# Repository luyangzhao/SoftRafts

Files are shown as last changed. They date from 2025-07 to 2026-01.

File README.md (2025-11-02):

# **SoftRafts: Floating and Adaptive Soft Modular Robots**

## 🚀 Overview

**SoftRafts** is a modular soft robotic system that integrates rigid 3D-printed components, soft foam, a cable-driven actuation mechanism, and a propeller for aquatic mobility. Using permanent magnets for fast inter-module connections, each unit can **bend**, **steer**, **connect**, and operate collectively in a swarm. It serves multiple functions, such as:

* Acting as a **gripper** to retrieve debris from water  
* Assembling into a **floating raft** for drone landing  
* Forming a **snake-like chain** that transitions between land and water  
* Working collaboratively to **transport payloads**

This platform demonstrates how soft deformation and modularity enable adaptive, multifunctional robotics for real-world aquatic environments.

---

## 📁 Repository Structure

```
SoftRafts/
│
├── CAD/                     # STL models for 3D printing
│   └── softraft.png         # Render of full assembled raft
│
├── firmware/                # ESP32-S2 microcontroller firmware
│   └── firmware_softrafts.ino
│
├── software/                # Control, analysis, and visualization notebooks
│   ├── SoftRafts-control.ipynb
│   ├── snake--curve.ipynb
│   └── gaits_data_processing.ipynb
│
├── raw_gaits_data/          # Raw positional and orientational data (6 gaits)
│   ├── forward_data.json
│   ├── backward_data.json
│   ├── left_front_data.json
│   ├── right_front_data.json
│   ├── left_back_data.json
│   ├── right_back_data.json
│   └── README.md
│
├── figures/                 # Auto-generated plots (e.g., Figure 8)
│   └── plot_comparison.png
│
├── LICENSE
└── README.md
```

---

## 🧱 CAD Models

The `CAD/` folder contains 3D-printable STL models for all robot parts:

* `Whole_SoftRaft.stl` — complete raft assembly (for reference)  
* `Board.stl`, `Middle.stl`, `Tail.stl`, `Head.stl` — core structural modules  
* `Motor.stl`, `Motor Cover.stl` — motor housing components  
* `Winch.stl` — for cable-driven actuation  
* `Cover.stl` — protective enclosure for electronics  
* `softraft.png` — visual rendering of the assembled robot  

---

## 🔧 Firmware

Located in the `firmware/` folder, `firmware_softrafts.ino` is the control firmware for the **ESP32-S2** microcontroller.

**Features:**
* Wi-Fi web server interface for motor control (port 80)  
* OTA (Over-the-Air) firmware updates via ArduinoOTA  
* Encoder-based position feedback and calibration  
* REST-style HTTP commands for live control (`/set`, `/status`, `/pause`, etc.)

> Upload via the **Arduino IDE** with the ESP32-S2 board selected.

---

## 🧠 Software

The `software/` folder contains all Python-based notebooks for **robot control, gait data analysis, and visualization**.

### Included Notebooks:
- **`SoftRafts-control.ipynb`** — Wi-Fi control interface for the SoftRaft robot  
- **`snake--curve.ipynb`** — Geometry and curvature visualization of chained modules  
- **`gaits_data_processing.ipynb`** — Reproducible gait data processing and analysis notebook for Figure 8

The analysis notebook:
* Loads raw data from `raw_gaits_data/`  
* Performs coordinate transformation to the local reference frame  
* Removes outliers and computes cluster centers  
* Generates the comparison figure automatically (`figures/plot_comparison.png`)

> Requires Python ≥ 3.7 with `numpy`, `matplotlib`, `requests`, `pandas`, and `notebook`.

---

## 📊 Raw Data

The `raw_gaits_data/` folder contains six JSON files corresponding to different gaits  
(forward, backward, left-front, right-front, left-back, right-back).  
Each file contains 35 recorded trials of positional and orientational data (in cm and degrees).

A detailed `README.md` in that folder explains:
* The meaning and units of each field  
* How to reproduce Figure 8 using the analysis notebook in `software/`

---

## ⚙️ Setup Instructions

1. Clone the repository:
   ```bash
   git clone https://github.com/SMILE-Robotics-Lab/SoftRafts.git
   cd SoftRafts/software
   ```

2. Create and activate a virtual environment:
   ```bash
   python3 -m venv venv
   source venv/bin/activate
   ```

3. Install dependencies:
   ```bash
   pip install numpy matplotlib pandas requests notebook
   ```

4. Launch Jupyter:
   ```bash
   jupyter notebook
   ```

---

## 📬 Contact

For questions, collaboration, or reproducibility assistance:

📧 **Luyang Zhao** — [luyangz@clemson.edu](mailto:luyangz@clemson.edu)  
📧 **Yitao Jiang** — [yitao.jiang.gr@dartmouth.edu](mailto:yitao.jiang.gr@dartmouth.edu)

---

## 📄 License

This project is licensed under the **MIT License**.

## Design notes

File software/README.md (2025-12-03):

# 🧠 SoftRafts Software

This folder contains Python-based control, analysis, and visualization notebooks for **SoftRafts**, supporting real-time robot control, geometric behavior visualization, and data processing for gait characterization.

---

## 📁 Files

### `SoftRafts-control.ipynb`

A **Jupyter notebook interface** for controlling the SoftRaft robot wirelessly via Wi-Fi.

🔧 **Features**:
* Sends HTTP commands (e.g., `/set`, `/status`, `/pause`) to the onboard ESP32  
* Adjusts motor positions, power, and direction  
* Displays returned status (position, power, battery, etc.)  
* Supports interactive testing of firmware APIs  

📦 **Requirements**:
* `requests`
* `IPython.display`
* Python ≥ 3.7

---

### `snake--curve.ipynb`

A notebook for **visualizing the geometry and curvature** of multi-module snake-like raft configurations.

📐 **Highlights**:
* Computes bend angles (`θ`) and link lengths (`s1`, `s2`) using trigonometry  
* Draws intermediate bend points (`C`, `D`) between modules  
* Propagates curvature along chained modules  
* Estimates directionality and turning radius  

📦 **Requirements**:
* `numpy`
* `matplotlib`

---

### `gaits_data_processing.ipynb`

A **standalone Jupyter notebook** that processes and analyzes the raw gait data used in the paper (Figure 8).  
It provides a fully reproducible pipeline from raw measurements to the final figure.

📊 **Functions**:
* Loads the six JSON files from [`../raw_gaits_data/`](../raw_gaits_data/)  
* Transforms data from distance/orientation changes into a standardized local reference frame  
* Removes outliers using the IQR method  
* Computes gait-specific cluster centers  
* Generates and saves the comparison figure (`../figures/plot_comparison.png`)  

📦 **Requirements**:
* `numpy`
* `matplotlib`
* `json`
* `pathlib`
* `pandas`

---

### `workspace/`

A **MATLAB** subfolder containing scripts for structural and workspace analysis of SoftRafts.  
Run **`MAIN_space.m`** to compute and visualize the robot’s workspace and deformation behavior under different prestress configurations.

📐 **Highlights**:
* Implements tensegrity equilibrium and stiffness matrix calculations  
* Visualizes deformation, workspace boundaries, and adaptation strategies  
* Includes supporting MATLAB functions for prestress design and plotting  

> 💡 Tested with MATLAB R2023a; requires the Optimization Toolbox.

---

## 🧰 Setup

Create a virtual environment and install dependencies:

```bash
python3 -m venv venv
source venv/bin/activate
pip install numpy matplotlib requests pandas notebook

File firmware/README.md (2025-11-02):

# 📡 SoftRafts Firmware

This folder contains the Arduino-based firmware (`firmware_softrafts.ino`) for the **ESP32-S2** microcontroller onboard each SoftRaft module. It enables real-time wireless control of motors, position feedback via encoders, and OTA (Over-the-Air) firmware updates.

---

## 🔌 Features

* ✅ Controls **3 motors** (2 motor actuators, 1 propulsion)
* ✅ Reads **quadrature encoders** for M1 and M2
* ✅ Supports **position control**, **power modulation**, and **direction switching**
* ✅ Hosts a **web server** on port `80` for HTTP-based control
* ✅ Supports **OTA updates** using `ArduinoOTA`
* ✅ Reports **battery voltage**, motor errors, and pause state

---

## 📁 File

* `firmware_softrafts.ino`: Main control firmware for SoftRaft hardware (ESP32)

---

## 🌐 Command Interface (via HTTP GET)

| Command | URL Format | Description |
| --- | --- | --- |
| Status | `/status` | Returns system status (motor position, power, battery, errors) |
| Set Motors | `/set=XXXXXXXXXXXXXX` | Set targets/powers for M1, M2, M3. Format: 8+2+8+2+1+2 hex chars |
| Calibrate | `/calibrate=XY` | Reset M1 and/or M2 encoder to zero |
| Reach Target | `/reach=XY` | Snap current position to target (for M1 and/or M2) |
| Pause/Resume | `/pause=X` | Pause (`1`) or resume (`0`) all motors |

Example:

```
/set=000000640A000000C80A11
```

sets:

* M1 target = 100 (0x00000064), power = 10
* M2 target = 200 (0x000000C8), power = 10
* M3 direction = `1` (forward), power = 17

---

## 📶 Wi-Fi Setup

The ESP32-S2 connects to:

* **SSID**: `BotTest`
* **Password**: `123456789`

You can modify these at the top of `firmware_softrafts.ino`.

Once connected, you can check the IP address and MAC address over your router portal.

---

## ⚙️ First Time Flashing Instructions

1. Open `firmware_softrafts.ino` in the Arduino IDE
2. Select **ESP32S2 Dev Module** as the board
3. Install required library:

   * `ArduinoOTA.h`
4. Connect the ESP32-S2 via USB and upload
5. After upload, monitor via serial to confirm Wi-Fi and OTA readiness

---

## 🔄 OTA Updates

Once connected to Wi-Fi, you can push firmware updates wirelessly using ArduinoOTA. The device will blink its onboard LED during OTA transfer.

---

## 📞 Troubleshooting

* Ensure your router allows devices to connect over 2.4GHz Wi-Fi.
* Use Serial Monitor to debug IP address and errors.

---

## 📜 License

This firmware is released under the [MIT License](../LICENSE).

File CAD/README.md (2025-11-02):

# **SoftRafts CAD Models and 3D Printing Guide**

## 🏗️ Overview

This folder contains **3D models** for all key components of **SoftRafts**, supporting modular design and assembly for soft robotic rafts.

### **🔹 Full SoftRaft Assembly**

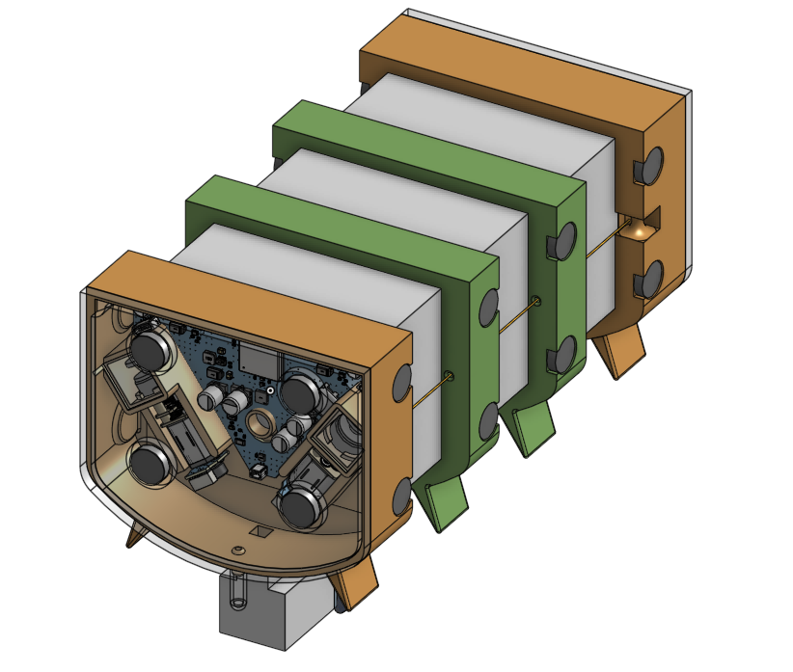
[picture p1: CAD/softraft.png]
SoftRaft Full Assembly


---

## 📂 Files in this Folder

* `Whole_SoftRaft.stl` → Assembled complete raft for reference or full printing.
* `Board.stl` → Main base board structure.
* `Tail.stl` → Rear-end module for propulsion or structure.
* `Middle.stl` → Central body segment for structural extension.
* `Motor Cover.stl` → Protective shell for the motor enclosure.
* `Motor.stl` → Motor housing unit.
* `Cover.stl` → General-purpose cover or enclosure.
* `Winch.stl` → Mechanical winch for tensioning or cable deployment.
* `Head.stl` → Frontal module, possibly for sensor mounting.
* `softraft.png` → Rendered image of the complete SoftRaft assembly.

---

## 🔩 **Component Descriptions**

### **1️⃣ Whole Assembly (`Whole_SoftRaft.stl`)**

* Fully assembled reference model combining all modules.
* Use for **scale check, visualization** prototypes.

---

### **2️⃣ Modular Parts**

#### `Board.stl`, `Tail.stl`, `Middle.stl`, `Head.stl`

* These represent the **core structural elements** of the raft.
* Can be printed and assembled modularly to form the complete raft body.

#### `Motor.stl` & `Motor Cover.stl`

* Designed to house compact **brushless or geared motors** for thrust or steering.

#### `Winch.stl`

* Winch mechanism base to integrate cable or string-based actuation or payload release.

#### `Cover.stl`

* A universal part used to seal components such as battery chambers or electronics.

**🔧 General Printing Guidelines for All Parts:**

* **Material**: PLA or PETG for general use; Resin for waterproof versions
* **Layer Height**: 0.15–0.2 mm
* **Supports**: Enabled for overhangs (e.g., motor housing)

---

## 🔧 **Modifying the CAD Models**

* For Fusion 360 or SolidWorks editing, convert STL to mesh body or re-model using `Whole_SoftRaft.stl` as reference.
* Recommended to re-export assemblies from native CAD format for major modifications.

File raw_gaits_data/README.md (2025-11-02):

# Raw Gait Data for SoftRafts (Used in Figure 8)

This folder contains the **raw positional and orientational data** used to generate **Figure 8** in the paper:  
*“Comparison of x–y positions for different gaits and their corresponding cluster centers with positions and orientations.”*

---

## Folder Contents

| File | Description |
|---|---|
| `forward_data.json` | Raw trajectory data for the forward gait |
| `backward_data.json` | Raw trajectory data for the backward gait |
| `left_front_data.json` | Raw trajectory data for the left-front gait |
| `right_front_data.json` | Raw trajectory data for the right-front gait |
| `left_back_data.json` | Raw trajectory data for the left-back gait |
| `right_back_data.json` | Raw trajectory data for the right-back gait |

Each file contains **recorded trials** of that gait, each stored as one JSON object per line.

---

## Data Format

Every JSON line includes the following fields:

| Key | Description | Unit |
|-----|---|---|
| `robot_id` | Robot identifier (constant = 2) | — |
| `tag_id` | AprilTag marker ID used for tracking | — |
| `start_x`, `start_y`, `start_theta` | Start position and orientation in the world (AprilTag) frame | **cm**, degrees |
| `goal_x`, `goal_y`, `goal_theta` | Final position and orientation after one gait cycle | **cm**, degrees |

All positions are expressed in the **AprilTag world coordinate frame**,  
with the robot’s initial pose standardized to \((0, 0, 0)\) and the orientation parallel to the x-axis.

---

## Processing and Reproduction

The Jupyter notebook [`../software/gaits_data_processing.ipynb`](../software/gaits_data_processing.ipynb)  
loads these JSON files, removes outliers, computes cluster centers,  
and reproduces **Figure 8** (the comparison of \(x\)–\(y\) positions and orientations).

Example usage:

```python
import json
from pathlib import Path

DATA_DIR = Path("../raw_gaits_data")
with open(DATA_DIR / "forward_data.json") as f:
    data = [json.loads(line) for line in f]

print(f"Loaded {len(data)} trials.")
print(data[0])

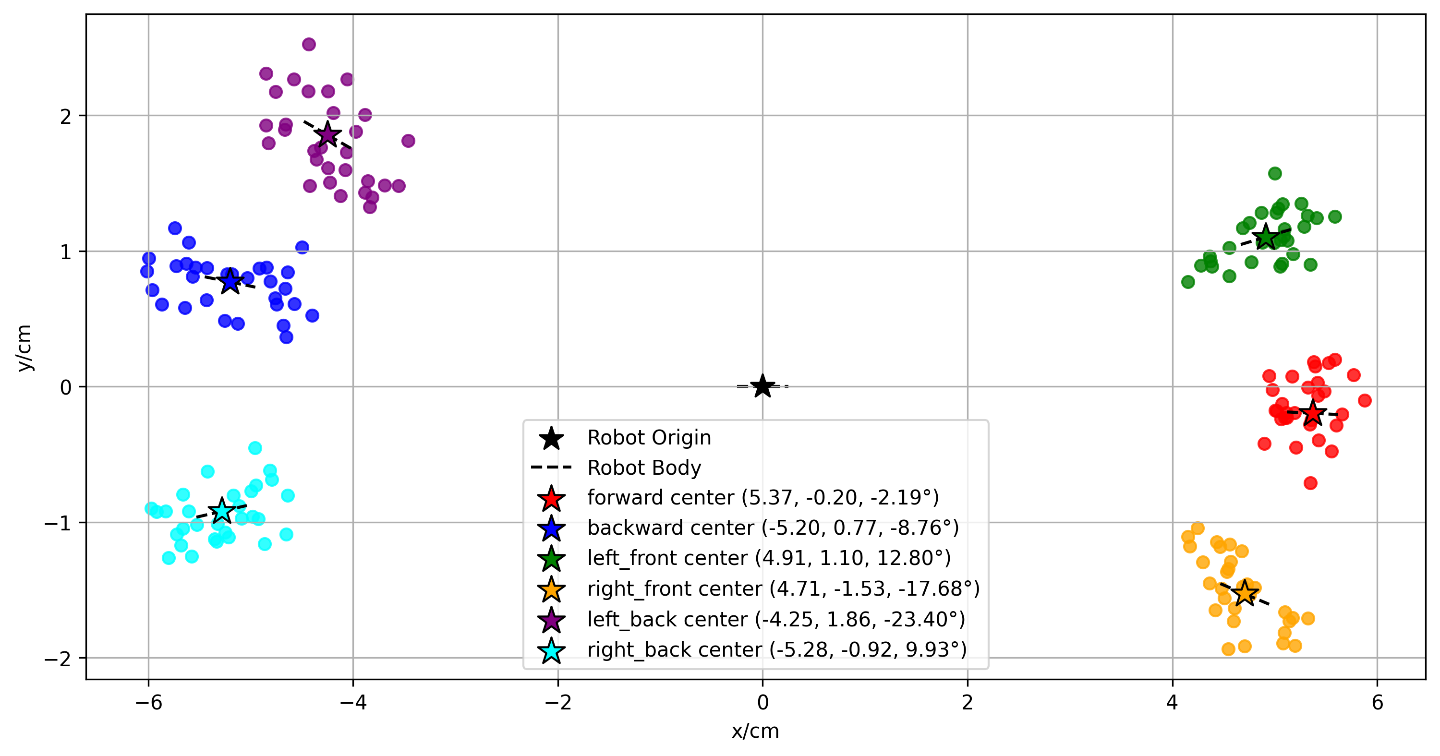
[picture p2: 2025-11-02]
figures/plot_comparison.png

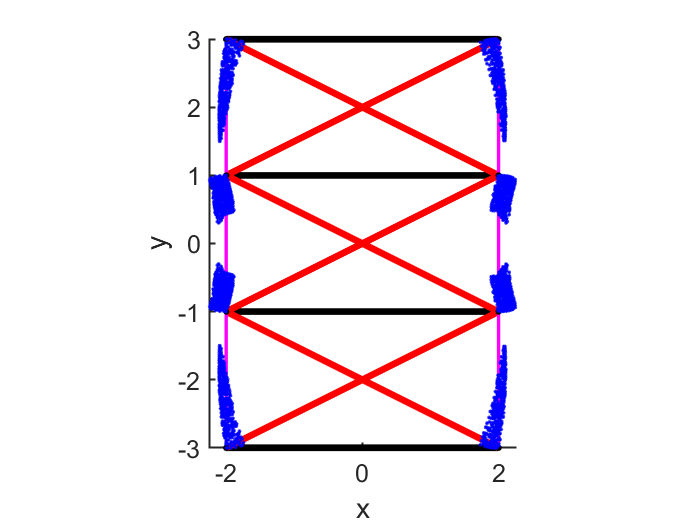
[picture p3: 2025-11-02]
software/workspace/new_v_workspace.png

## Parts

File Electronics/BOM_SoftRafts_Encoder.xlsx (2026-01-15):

No. | Quantity | Device | Designator | Footprint | Value | Manufacturer Part | Manufacturer | Supplier Part | Supplier | JLCPCB Part Class
1 | 1 | CL05A105KA5NQNC | C1 | C0402 | 1uF | CL05A105KA5NQNC | SAMSUNG(三星) | C52923 | LCSC | Basic Part
2 | 1 | CL05B104KB54PNC | C2 | C0402 | 100nF | CL05B104KB54PNC | SAMSUNG(三星) | C307331 | LCSC | Basic Part
3 | 1 | 1.0-6PS | CN1 | CONN-SMD_6P-P1.00_DEALON_1.0-6PS |  | 1.0-6PS | DEALON(德艺隆) | C2904988 | LCSC | Extended Part
4 | 2 | 0402WGF2201TCE | R1,R2 | R0402 | 2.2kΩ | 0402WGF2201TCE | UNI-ROYAL(厚声) | C25879 | LCSC | Basic Part
5 | 2 | DRV5013ADQDBZR | U1,U2 | SOT-23-3_L2.9-W1.3-P1.90-LS2.4-BR |  | DRV5013ADQDBZR | TI(德州仪器) | C575585 | LCSC | Extended Part

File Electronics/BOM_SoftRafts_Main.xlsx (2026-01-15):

No. | Quantity | Device | Designator | Footprint | Value | Manufacturer Part | Manufacturer | Supplier Part | Supplier | JLCPCB Part Class
1 | 2 | Test-Point | BOOT,EN | test-point-0.5mm
2 | 6 | 126RV0010 | C1,C17,C18,C19,C40,C41 | CAP-SMD_BD6.3-L6.6-W6.6-FD | 470uF | 126RV0010 | KNSCHA(科尼盛) | C5354997 | LCSC | Extended Part
3 | 4 | CL05A105KA5NQNC | C2,C3,C15,C16 | C0402 | 1uF | CL05A105KA5NQNC | SAMSUNG(三星) | C52923 | LCSC | Basic Part
4 | 9 | CL21A226MAQNNNE | C4,C5,C7,C30,C31,C32,C33,C34,C35 | C0805 | 22uF | CL21A226MAQNNNE | SAMSUNG(三星) | C45783 | LCSC | Basic Part
5 | 2 | CL31A107MQHNNNE | C6,C29 | C1206 | 100uF | CL31A107MQHNNNE | SAMSUNG(三星) | C15008 | LCSC | Basic Part
6 | 7 | CL05B104KB54PNC | C8,C9,C10,C11,C37,C38,C39 | C0402 | 100nF | CL05B104KB54PNC | SAMSUNG(三星) | C307331 | LCSC | Basic Part
7 | 1 | CL10A106MA8NRNC | C20 | C0603 | 10uF | CL10A106MA8NRNC | SAMSUNG(三星) | C96446 | LCSC | Basic Part
8 | 2 | 1.0-6PS | CN2,CN3 | CONN-SMD_6P-P1.00_DEALON_1.0-6PS |  | 1.0-6PS | DEALON(德艺隆) | C2904988 | LCSC | Extended Part
9 | 1 | 1.0-2PS | CN4 | CONN-SMD_2P-P1.0-2PS-LT |  | 1.0-2PS | DEALON(德艺隆) | C2904984 | LCSC | Extended Part
10 | 1 | 1N5819WS_C191023 | D1 | SOD-323_L1.8-W1.3-LS2.5-RD |  | 1N5819WS | Hottech(合科泰) | C191023 | LCSC | Basic Part
11 | 3 | SS54_C22452 | D3,D4,D5 | SMA_L4.4-W2.8-LS5.4-R-RD |  | SS54 | MDD | C22452 | LCSC | Basic Part
12 | 3 | FNR4030S6R8MT | L1,L2,L3 | IND-SMD_L4.0-W4.0_FNR4012S | 6.8uH | FNR4030S6R8MT | cjiang(长江微电) | C167876 | LCSC | Extended Part
13 | 1 | KT-0603R | LED1 | LED0603-RD |  | KT-0603R | KENTO | C2286 | LCSC | Basic Part
14 | 1 | KT-0603W | LED2 | LED0603-RD |  | KT-0603W | KENTO | C2290 | LCSC | Basic Part
15 | 3 | 0402WGF1743TCE | R1,R12,R14 | R0402 | 174kΩ | 0402WGF1743TCE | UNI-ROYAL(厚声) | C26994 | LCSC | Extended Part
16 | 3 | 0402WGF1002TCE | R2,R13,R15 | R0402 | 10kΩ | 0402WGF1002TCE | UNI-ROYAL(厚声) | C25744 | LCSC | Basic Part
17 | 4 | 0402WGF1001TCE | R3,R7,R8,R9 | R0402 | 1kΩ | 0402WGF1001TCE | UNI-ROYAL(厚声) | C11702 | LCSC | Basic Part
18 | 3 | 0402WGF5101TCE | R4,R5,R6 | R0402 | 5.1kΩ | 0402WGF5101TCE | UNI-ROYAL(厚声) | C25905 | LCSC | Basic Part
19 | 2 | RL0805FR-070R04L | R16,R17 | R0805 | 40mΩ | RL0805FR-070R04L | YAGEO(国巨) | C326963 | LCSC | 扩展库
20 | 6 | 0402WGF470KTCE | R19,R20,R21,R22,R23,R24 | R0402 | 4.7Ω | 0402WGF470KTCE | UNI-ROYAL(厚声) | C25121 | LCSC | 扩展库
21 | 1 | HoLR1206-1W-20mR-1%-75ppm | R25 | R1206 | 20mΩ | HoLR1206-1W-20mR-1%-75ppm | Milliohm(毫欧) | C601099 | LCSC | 扩展库
22 | 1 | RT9013-33GB | U1 | SOT-23-5_L3.0-W1.7-P0.95-LS2.8-BL |  | RT9013-33GB | RICHTEK(立锜) | C47773 | LCSC | Extended Part
23 | 3 | MT3608 | U2,U8,U9 | SOT-23-6_L2.9-W1.6-P0.95-LS2.8-BL |  | MT3608 | 西安航天民芯 | C84817 | LCSC | Extended Part
24 | 1 | ESP32-S2-MINI-2-N4 | U3 | WIFI-SMD_ESP32-MINI-1-N4 | 2.4GHz | ESP32-S2-MINI-2-N4 | ESPRESSIF(乐鑫) | C3013906 | LCSC | Extended Part
25 | 3 | DRV8837DSGR | U4,U5,U6 | WSON-8_L2.0-W2.0-P0.50-TL-EP |  | DRV8837DSGR | TI(德州仪器) | C39159 | LCSC | Extended Part
26 | 1 | INA3221AIRGVR | U7 | QFN-16_L4.0-W4.0-P0.65-TL-EP2.2 |  | INA3221AIRGVR | TI(德州仪器) | C181255 | LCSC | 扩展库
27 | 1 | TYPE-C 16PIN 2MD(073) | USB1 | USB-C-SMD_TYPE-C-6PIN-2MD-073 |  | TYPE-C 16PIN 2MD(073) | SHOU HAN(首韩) | C2765186 | LCSC | Extended Part

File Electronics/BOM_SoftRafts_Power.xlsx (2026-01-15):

No. | Quantity | Device | Designator | Footprint | Value | Manufacturer Part | Manufacturer | Supplier Part | Supplier | JLCPCB Part Class
1 | 4 | AO3401A_C15127 | Q1,Q2,Q3,Q4 | SOT-23_L2.9-W1.3-P1.90-LS2.4-BR |  | AO3401A | AOS | C15127 | LCSC | 基础库
2 | 2 | 0402WGF1002TCE | R101,R102 | R0402 | 10kΩ | 0402WGF1002TCE | UNI-ROYAL(厚声) | C25744 | LCSC | 基础库
3 | 1 | SN74LVC1G80DCKR | U101 | SC-70-5_L2.1-W1.3-P0.65-LS2.1-BL |  | SN74LVC1G80DCKR | TI(德州仪器) | C473331 | LCSC | 扩展库

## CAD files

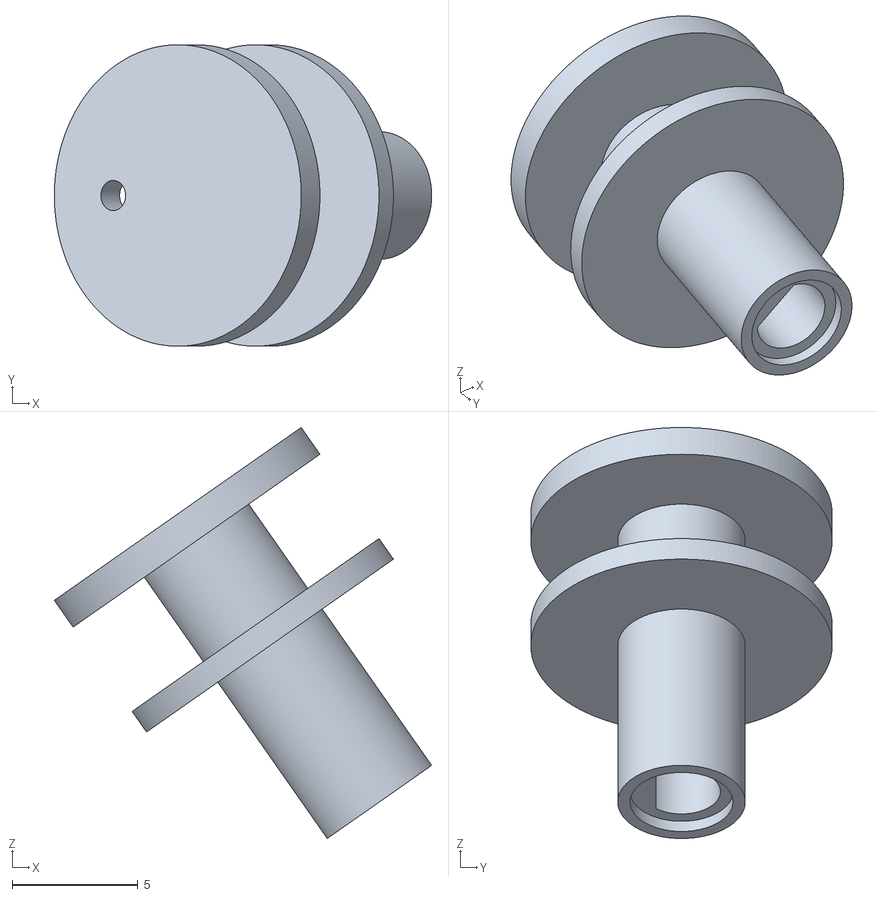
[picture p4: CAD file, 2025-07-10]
CAD/Winch.stl
15.0 x 12.0 x 16.4

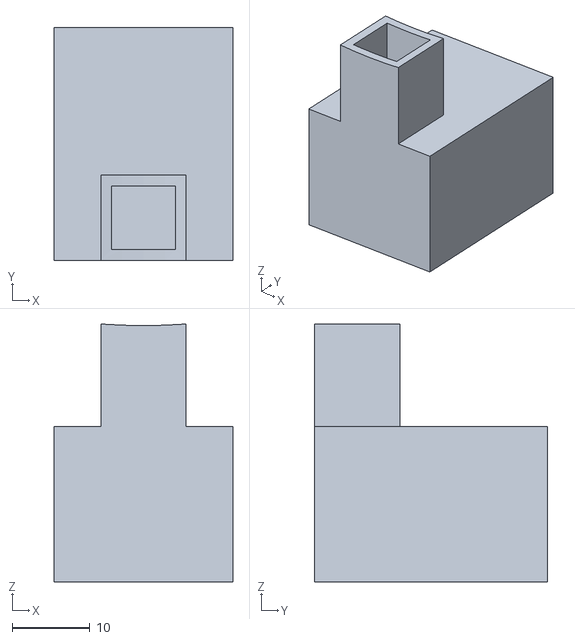
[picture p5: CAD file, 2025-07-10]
CAD/Motor.stl
23.0 x 30.0 x 33.2

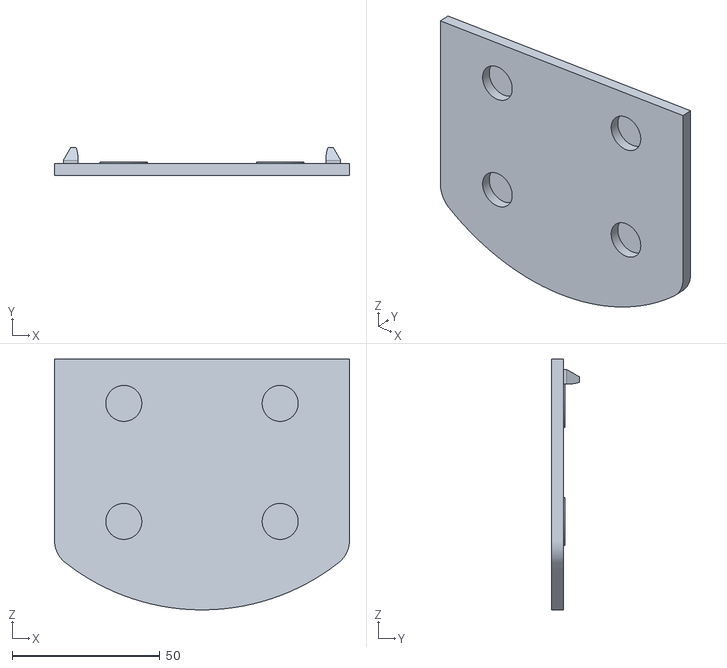
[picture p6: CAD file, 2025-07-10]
CAD/Cover.stl
100.0 x 9.50 x 85.0

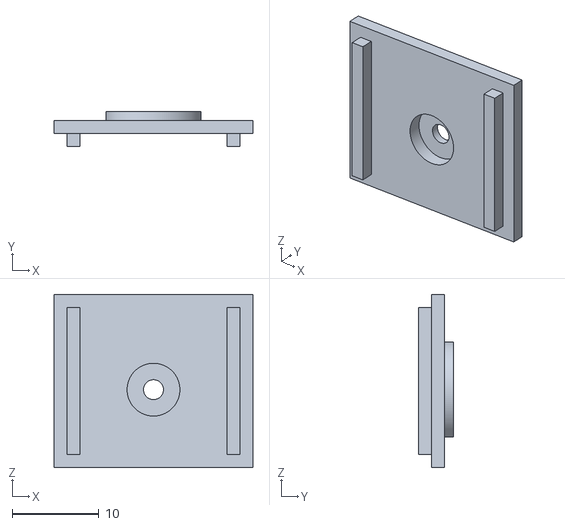
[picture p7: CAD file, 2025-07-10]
CAD/Motor Cover.stl
23.0 x 4.00 x 20.0

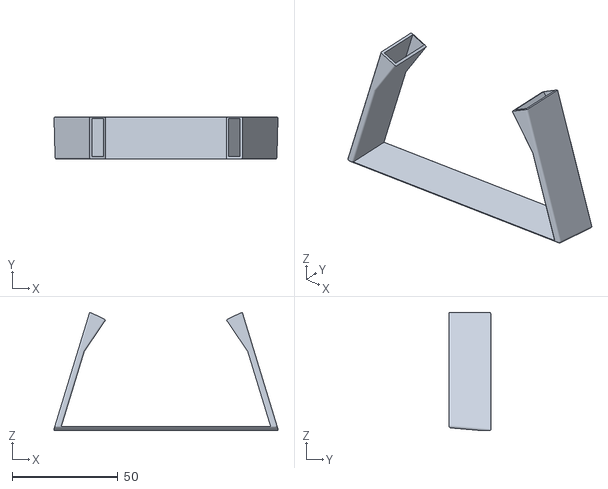
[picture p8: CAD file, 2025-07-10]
CAD/Board.stl
106.0 x 20.0 x 55.8

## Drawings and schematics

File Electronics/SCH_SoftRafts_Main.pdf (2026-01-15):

IO36 32 IO37 33 IO38 34 IO39 35 IO40 36 IO41 37 IO42 38 TXD0 39 RXD0 40 IO45 41 GND 42 GND 43 IO46 44 EN 45 GND 46 GND 47 GND 48 GND 49 GND 50 GND 51 GND 52 GND 53 GND 54 GND 55 GND 56 GND 57 GND 58 GND 59 GND 60 GND 61 GND 62 GND 63 GND 64 GND 65

## 20mVCC

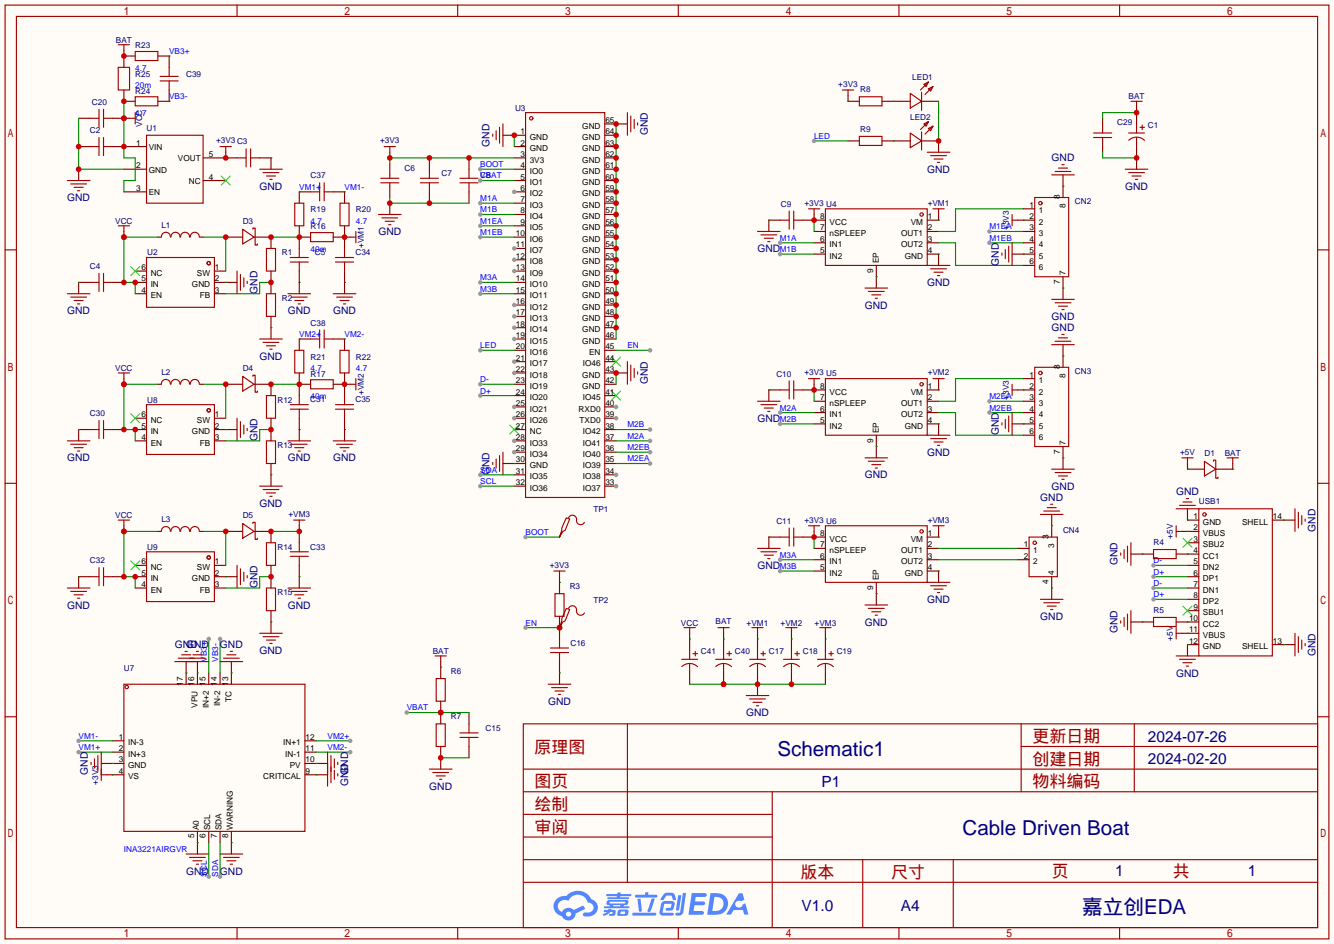
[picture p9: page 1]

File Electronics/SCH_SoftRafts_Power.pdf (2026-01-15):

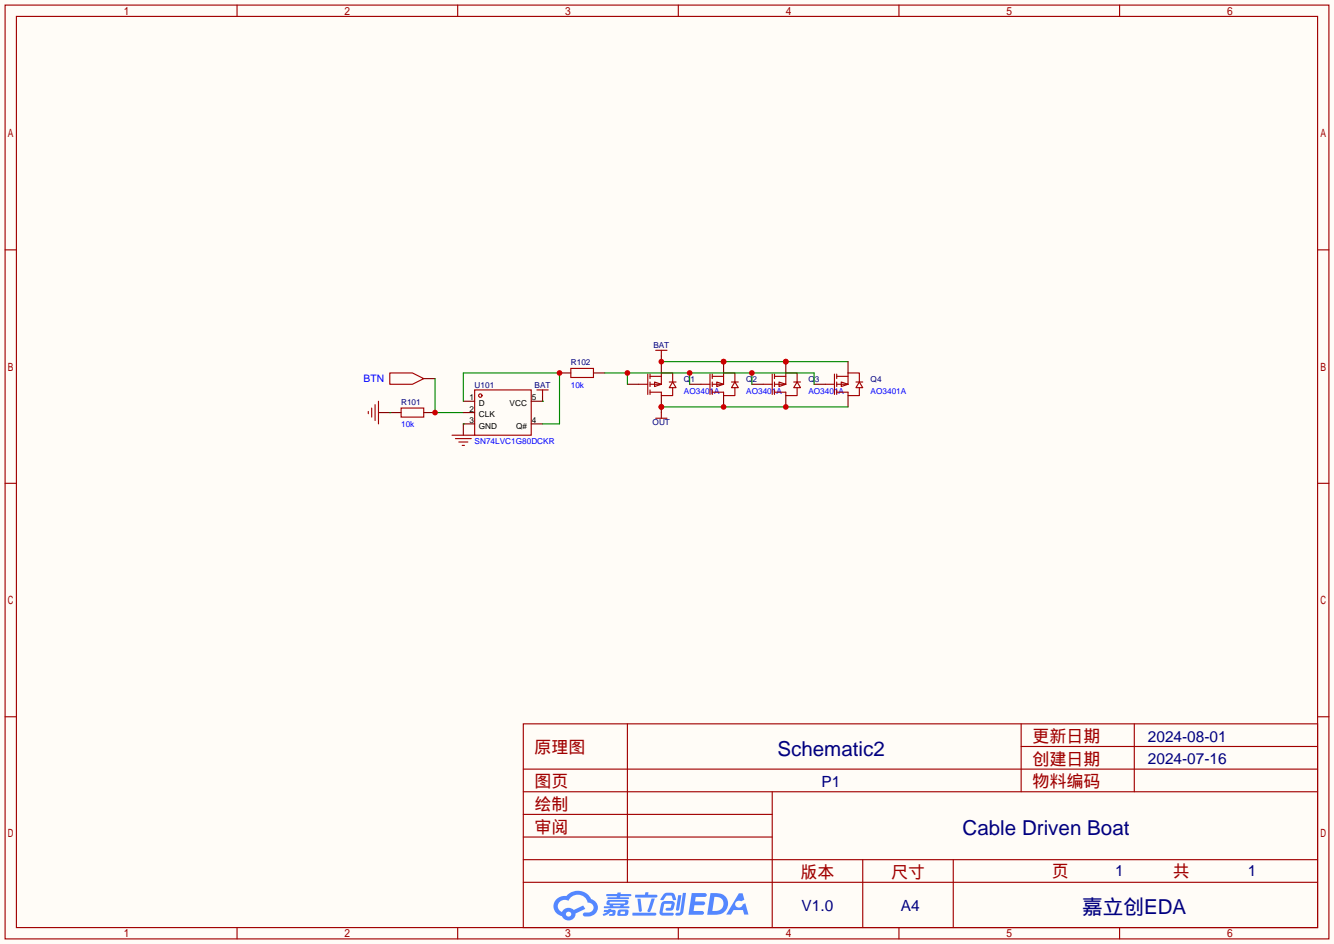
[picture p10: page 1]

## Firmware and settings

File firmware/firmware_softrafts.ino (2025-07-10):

#include <WiFi.h>
#include <ArduinoOTA.h>

static const int32_t tolerance = 30;

static const int M1A = 3;
static const int M1B = 4;
static const int M1EA = 5;
static const int M1EB = 6;
static const int M2A = 41;
static const int M2B = 42;
static const int M2EA = 39;
static const int M2EB = 40;
static const int M3A = 10;
static const int M3B = 11;
static const int LED = 16;
static const int VBAT = 1;

static const char *ssid = "BotTest";
static const char *password = "123456789";

// Set web server port number to 80
WiFiServer server(80);
// Variable to store the HTTP request
String header;

volatile int32_t M1_target = 0;
volatile int32_t M1_current = 0;
volatile int32_t M1_error = 0;
volatile uint8_t M1_power = 0;
volatile int32_t M2_target = 0;
volatile int32_t M2_current = 0;
volatile int32_t M2_error = 0;
volatile uint8_t M2_power = 0;
volatile bool M3_direction = true;
volatile uint8_t M3_power = 0;
volatile bool pause_bot = false;

volatile uint8_t M1_rec, M2_rec;

void motor()
{
  if (M1_target - tolerance > M1_current && !pause_bot)
  {
    ledcWrite(M1A, M1_power);
    ledcWrite(M1B, 0);
  }
  else if (M1_target + tolerance < M1_current && !pause_bot)
  {
    ledcWrite(M1A, 0);
    ledcWrite(M1B, M1_power);
  }
  else
  {
    ledcWrite(M1A, 0);
    ledcWrite(M1B, 0);
  }
  if (M2_target - tolerance > M2_current && !pause_bot)
  {
    ledcWrite(M2A, M2_power);
    ledcWrite(M2B, 0);
  }
  else if (M2_target + tolerance < M2_current && !pause_bot)
  {
    ledcWrite(M2A, 0);
    ledcWrite(M2B, M2_power);
  }
  else
  {
    ledcWrite(M2A, 0);
    ledcWrite(M2B, 0);
  }
  if (M3_direction && !pause_bot)
  {
    ledcWrite(M3A, M3_power);
    ledcWrite(M3B, 0);
  }
  else if (!M3_direction && !pause_bot)
  {
    ledcWrite(M3A, 0);
    ledcWrite(M3B, M3_power);
  }
  else
  {
    ledcWrite(M3A, 0);
    ledcWrite(M3B, 0);
  }
}

void IRAM_ATTR isr()
{
  uint8_t M1_now = (digitalRead(M1EA) << 1) | digitalRead(M1EB);
  uint8_t M2_now = (digitalRead(M2EA) << 1) | digitalRead(M2EB);

  // 00,01,11,10
  if ((M1_rec == 0b00 && M1_now == 0b01) || (M1_rec == 0b01 && M1_now == 0b11) || (M1_rec == 0b11 && M1_now == 0b10) || (M1_rec == 0b10 && M1_now == 0b00))
    M1_current++;
  else if ((M1_rec == 0b10 && M1_now == 0b11) || (M1_rec == 0b11 && M1_now == 0b01) || (M1_rec == 0b01 && M1_now == 0b00) || (M1_rec == 0b00 && M1_now == 0b10))
    M1_current--;
  else if (M1_rec != M1_now)
    M1_error++;
  if ((M2_rec == 0b00 && M2_now == 0b01) || (M2_rec == 0b01 && M2_now == 0b11) || (M2_rec == 0b11 && M2_now == 0b10) || (M2_rec == 0b10 && M2_now == 0b00))
    M2_current++;
  else if ((M2_rec == 0b10 && M2_now == 0b11) || (M2_rec == 0b11 && M2_now == 0b01) || (M2_rec == 0b01 && M2_now == 0b00) || (M2_rec == 0b00 && M2_now == 0b10))
    M2_current--;
  else if (M2_rec != M2_now)
    M2_error++;

  M1_rec = M1_now;
  M2_rec = M2_now;

  motor();
}

long HexToLong(String s)
{
  char arr[13] = {0};
  s.toCharArray(arr, sizeof(arr));
  volatile long result = 0;
  for (uint8_t i = 0; i < 12 && arr[i] != 0; i++) {
    if (arr[i] >= '0' && arr[i] <= '9') {
      result <<= 4;
      result |= (arr[i] - '0');
    }
    else if (arr[i] >= 'A' && arr[i] <= 'F') {
      result <<= 4;
      result |= (arr[i] - 'A' + 10);
    }
  }
  return result;
}

float getBattery()
{
  int temp = 0;
  for(int i=0;i<8;i++)
    temp += analogRead(VBAT);
  return (float)temp * 0.0000765735320709761f + 0.04f;
}

void setup()
{
  Serial.begin(115200);

  pinMode(LED, OUTPUT);
  digitalWrite(LED, HIGH);
  
  ledcAttach(M1A, 50000, 8);
  ledcAttach(M1B, 50000, 8);
  ledcAttach(M2A, 50000, 8);
  ledcAttach(M2B, 50000, 8);
  ledcAttach(M3A, 50000, 8);
  ledcAttach(M3B, 50000, 8);
  ledcWrite(M1A, 0);
  ledcWrite(M1B, 0);
  ledcWrite(M2A, 0);
  ledcWrite(M2B, 0);
  ledcWrite(M3A, 0);
  ledcWrite(M3B, 0);

  pinMode(VBAT, INPUT);
  analogSetAttenuation(ADC_0db);
  pinMode(M1EA, INPUT);
  pinMode(M1EB, INPUT);
  pinMode(M2EA, INPUT);
  pinMode(M2EB, INPUT);
  attachInterrupt(M1EA, isr, CHANGE);
  attachInterrupt(M1EB, isr, CHANGE);
  attachInterrupt(M2EA, isr, CHANGE);
  attachInterrupt(M2EB, isr, CHANGE);

  M1_rec = (digitalRead(M1EA) << 1) | digitalRead(M1EB);
  M2_rec = (digitalRead(M2EA) << 1) | digitalRead(M2EB);
  delay(500);
  digitalWrite(LED, LOW);

  // Connect to Wi-Fi network with SSID and password
  Serial.print("Connecting to ");
  Serial.println(ssid);
  WiFi.begin(ssid, password);
  while (WiFi.status() != WL_CONNECTED)
  {
    delay(500);
    Serial.print(".");
    digitalWrite(LED, !digitalRead(LED));
  }
  // Print local IP address and start web server
  Serial.println("");
  Serial.println("WiFi connected.");
  Serial.print("IP address: ");
  Serial.println(WiFi.localIP());
  Serial.print("MAC address: ");
  Serial.println(WiFi.macAddress());
  server.begin();

  ArduinoOTA
    .onStart([]() {
      String type;
      if (ArduinoOTA.getCommand() == U_FLASH)
        type = "sketch";
      else // U_SPIFFS
        type = "filesystem";

      // NOTE: if updating SPIFFS this would be the place to unmount SPIFFS using SPIFFS.end()
      Serial.println("Start updating " + type);
    })
    .onEnd([]() {
      Serial.println("\nEnd");
    })
    .onProgress([](unsigned int progress, unsigned int total) {
      Serial.printf("Progress: %u%%\r", (progress / (total / 100)));
      digitalWrite(LED, !digitalRead(LED));
    })
    .onError([](ota_error_t error) {
      Serial.printf("Error[%u]: ", error);
      if (error == OTA_AUTH_ERROR) Serial.println("Auth Failed");
      else if (error == OTA_BEGIN_ERROR) Serial.println("Begin Failed");
      else if (error == OTA_CONNECT_ERROR) Serial.println("Connect Failed");
      else if (error == OTA_RECEIVE_ERROR) Serial.println("Receive Failed");
      else if (error == OTA_END_ERROR) Serial.println("End Failed");
    });

  ArduinoOTA.begin();
  digitalWrite(LED, LOW);
}

void loop()
{
  ArduinoOTA.handle();
  WiFiClient client = server.available(); // Listen for incoming clients

  if (client)
  {                                 // If a new client connects,
    Serial.println("New Request."); // print a message out in the serial port
    String currentLine = "";        // make a String to hold incoming data from the client
    while (client.connected())
    { // loop while the client's connected
      if (client.available())
      {                         // if there's bytes to read from the client,
        char c = client.read(); // read a byte, then
        Serial.write(c);        // print it out the serial monitor
        header += c;
        if (c == '\n')
        { // if the byte is a newline character
          // if the current line is blank, you got two newline characters in a row.
          // that's the end of the client HTTP request, so send a response:
          if (currentLine.length() == 0)
          {
            // HTTP headers always start with a response code (e.g. HTTP/1.1 200 OK)
            // and a content-type so the client knows what's coming, then a blank line:
            client.println("HTTP/1.1 200 OK");
            client.println("Content-type:application/json");
            client.println("Connection: close");
            client.println();

            // GET /?status HTTP/1.1
            if (header.indexOf("status") >= 0)
            {
              Serial.println("status requested");
              // Get the status of the system
              // Including IP address, MAC address, current position (M1, M2), target position (M1, M2), current power (M1, M2, M3), error (M1, M2), battery, pause
              client.println("{\"status\":\"ok\", \"ip\":\"" + WiFi.localIP().toString() + "\", \"mac\":\"" + String(WiFi.macAddress()) + "\", \"m1_current\":" + M1_current + ", \"m1_target\":" + M1_target + ", \"m2_current\":" + M2_current + ", \"m2_target\":" + M2_target + ", \"m1_power\": " + M1_power + ", \"m2_power\": " + M2_power + ", \"m3_power\": " + M3_power + ", \"m1_error\": " + M1_error + ", \"m2_error\": " + M2_error + ", \"battery\": " + getBattery() + ", \"pause\":" + (pause_bot ? String("true") : String("false")) + "}");
            }
            else if (header.indexOf("set") >= 0)
            {
              Serial.println("set requested");
              // Set the target and power of motors
              // Format: /set=[M1 position, HEX8][M1 power, HEX2][M2 position, HEX8][M2 power, HEX2][M3 direction, bit][M3 power, HEX2]
              // Totally 22 characters in the parameter
              int pos = header.indexOf('=');
              String M1_pos = header.substring(pos + 1, pos + 9);
              String M1_pow = header.substring(pos + 9, pos + 11);
              String M2_pos = header.substring(pos + 11, pos + 19);
              String M2_pow = header.substring(pos + 19, pos + 21);
              String M3_dir = header.substring(pos + 21, pos + 22);
              String M3_pow = header.substring(pos + 22, pos + 24);
              M1_target = (int32_t)HexToLong(M1_pos);
              M1_power = (uint8_t)HexToLong(M1_pow);
              M2_target = (int32_t)HexToLong(M2_pos);
              M2_power = (uint8_t)HexToLong(M2_pow);
              M3_direction = M3_dir=="1" ? true : false;
              M3_power = (uint8_t)HexToLong(M3_pow);
              client.println("{\"status\":\"set ok\", \"ip\":\"" + WiFi.localIP().toString() + "\", \"mac\":\"" + String(WiFi.macAddress()) + "\", \"m1_current\":" + M1_current + ", \"m1_target\":" + M1_target + ", \"m2_current\":" + M2_current + ", \"m2_target\":" + M2_target + ", \"m1_power\": " + M1_power + ", \"m2_power\": " + M2_power + ", \"m3_power\": " + M3_power + ", \"m1_error\": " + M1_error + ", \"m2_error\": " + M2_error + ", \"battery\": " + getBattery() + ", \"pause\":" + (pause_bot ? String("true") : String("false")) + "}");
            }
            else if (header.indexOf("calibrate") >= 0)
            {
              Serial.println("calibrate requested");
              // Set target and current position to 0
              // Format: /calibrate=[M1, bit][M2, bit]
              // Totally 2 characters in the parameter
              int pos = header.indexOf('=');
              if (header.substring(pos + 1, pos + 2)[0] == '1')
              {
                M1_target = M1_current = 0;
              }
              if (header.substring(pos + 2, pos + 3)[0] == '1')
              {
                M2_target = M2_current = 0;
              }
              client.println("{\"status\":\"calibrate ok\", \"ip\":\"" + WiFi.localIP().toString() + "\", \"mac\":\"" + String(WiFi.macAddress()) + "\", \"m1_current\":" + M1_current + ", \"m1_target\":" + M1_target + ", \"m2_current\":" + M2_current + ", \"m2_target\":" + M2_target + ", \"m1_power\": " + M1_power + ", \"m2_power\": " + M2_power + ", \"m3_power\": " + M3_power + ", \"m1_error\": " + M1_error + ", \"m2_error\": " + M2_error + ", \"battery\": " + getBattery() + ", \"pause\":" + (pause_bot ? String("true") : String("false")) + "}");
            }
            else if (header.indexOf("reach") >= 0)
            {
              Serial.println("reach requested");
              // Set current position to target position
              // Format: /reach=[M1, bit][M2, bit]
              // Totally 2 characters in the parameter
              int pos = header.indexOf('=');
              if (header.substring(pos + 1, pos + 2)[0] == '1')
              {
                M1_current = M1_target;
              }
              if (header.substring(pos + 2, pos + 3)[0] == '1')
              {
                M2_current = M2_target;
              }
              client.println("{\"status\":\"reach ok\", \"ip\":\"" + WiFi.localIP().toString() + "\", \"mac\":\"" + String(WiFi.macAddress()) + "\", \"m1_current\":" + M1_current + ", \"m1_target\":" + M1_target + ", \"m2_current\":" + M2_current + ", \"m2_target\":" + M2_target + ", \"m1_power\": " + M1_power + ", \"m2_power\": " + M2_power + ", \"m3_power\": " + M3_power + ", \"m1_error\": " + M1_error + ", \"m2_error\": " + M2_error + ", \"battery\": " + getBattery() + ", \"pause\":" + (pause_bot ? String("true") : String("false")) + "}");
            }
            else if (header.indexOf("pause") >= 0)
            {
              Serial.println("pause requested");
              // Set current position to target position
              // Format: /pause=[pause/resume, bit]
              // Totally 2 characters in the parameter
              int pos = header.indexOf('=');
              if (header.substring(pos + 1, pos + 2)[0] == '0')
              {
                pause_bot = false;
              }
              else
              {
                pause_bot = true;
              }
              client.println("{\"status\":\"" + (pause_bot ? String("pause") : String("resume")) + " ok\", \"ip\":\"" + WiFi.localIP().toString() + "\", \"mac\":\"" + String(WiFi.macAddress()) + "\", \"m1_current\":" + M1_current + ", \"m1_target\":" + M1_target + ", \"m2_current\":" + M2_current + ", \"m2_target\":" + M2_target + ", \"m1_power\": " + M1_power + ", \"m2_power\": " + M2_power + ", \"m3_power\": " + M3_power + ", \"m1_error\": " + M1_error + ", \"m2_error\": " + M2_error + ", \"battery\": " + getBattery() + ", \"pause\":" + (pause_bot ? String("true") : String("false")) + "}");
            }
            else
            {
              Serial.println("error requested");
              client.println("{\"status\":\"error\", \"ip\":\"" + WiFi.localIP().toString() + "\", \"mac\":\"" + String(WiFi.macAddress()) + "\", \"m1_current\":" + M1_current + ", \"m1_target\":" + M1_target + ", \"m2_current\":" + M2_current + ", \"m2_target\":" + M2_target + ", \"m1_power\": " + M1_power + ", \"m2_power\": " + M2_power + ", \"m3_power\": " + M3_power + ", \"m1_error\": " + M1_error + ", \"m2_error\": " + M2_error + ", \"battery\": " + getBattery() + ", \"pause\":" + (pause_bot ? String("true") : String("false")) + "}");
            }
            // The HTTP response ends with another blank line
            client.println();
            // Break out of the while loop
            break;
          }
          else
          { // if you got a newline, then clear currentLine
            currentLine = "";
          }
        }
        else if (c != '\r')
        {                   // if you got anything else but a carriage return character,
          currentLine += c; // add it to the end of the currentLine
        }
      }
    }
    // Clear the header variable
    header = "";
    // Close the connection
    client.stop();
    Serial.println("Client disconnected.");
    Serial.println("");
    motor();
  }
}

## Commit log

2025-11-02 Revise material guidelines in README
    Updated material recommendations for waterproof versions.
2025-11-02 Update README to reflect ESP32-S2 board selection
2025-11-02 Revise README for motor terminology and flashing steps
    Updated terminology for motor actuators and clarified connection instructions. Revised flashing instructions for clarity and consistency.
2026-01-15 Add files via upload
    Upload electronics design source files.
    [BOM_SoftRafts_Encoder.xlsx, BOM_SoftRafts_Main.xlsx, BOM_SoftRafts_Power.xlsx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]
